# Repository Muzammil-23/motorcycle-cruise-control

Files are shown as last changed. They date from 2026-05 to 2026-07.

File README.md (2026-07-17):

# Low-Cost Cruise Control System for Honda CD70 (and similar 70-150cc motorcycles)



[]()

A retrofittable, low-cost cruise control system for small-displacement motorcycles (70-150cc) commonly found in South Asian and Southeast Asian markets. The system uses an Arduino Nano, Hall-effect speed sensor, MG996R servo, and a discrete-time PI controller to maintain a rider-set speed, and 1.2in OLED for UI. Improving comfort, fuel efficiency and reducing fatigue on long rides.

## 📋 Features

- **Closed-loop speed regulation** at 50 km/h setpoint (configurable)
- **Velocity-form PI controller** (Kp = 0.67, Ki = 0.48 s⁻¹) with 2 km/h dead-band
- **Moving average filter** (3 samples) for noise reduction
- **Safety disengagement** via brake, clutch, and kill switch
- **Hardware interrupt** for brake → fastest response (~500 ms)
- **OLED display** showing speed, setpoint, and system status
- **Bumpless transfer** on engagement/disengagement
- **Cost-effective** (~$20 USD total hardware cost)

 ## Cruise Control System installed on a motorcycle handlebar
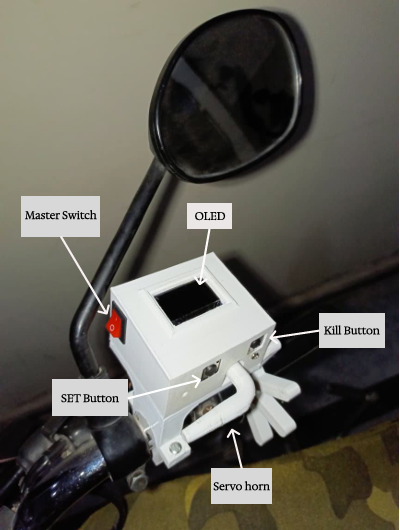
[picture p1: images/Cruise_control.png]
Cruise Control System installed on a motorcycle handlebar


## 🔧 Hardware

This project was designed using **Proteus 8 Professional** .

| Folder | Contents |
|---|---|
| `/schematic` | Proteus editable file (.pdsprj) and PDF schematic |
| `/PCB` | Gerber files (ZIP) for manufacturing and PDF layout |

## 💻 Firmware

The firmware runs on an **Arduino Nano** (ATmega328P).

**Required Libraries:**
- `Adafruit_SSD1306.h` (OLED display)
- `Adafruit_GFX.h` (graphics library)
- `Servo.h` (built-in)

**Upload Instructions:**
1. Open the `.ino` file in Arduino IDE
2. Select Board: Arduino Nano
3. Select Processor: ATmega328P
4. Upload via USB

## 🖨️ 3D Models

STL files for the enclosure and mechanical parts are in the `/3D files` folder.

**Printing Recommendations:**
- Material: ABS or PETG
- Layer height: 0.2mm
- Infill: 20%
- Supports: Yes (for specific parts - check individual files)

# Project Licensing

This project uses different licenses for different types of content:

| Content Type | License |
|---|---|
| Firmware (code in `/firmware` folder) | MIT License (see LICENSE file) |
| Hardware (schematics, PCB layouts, BOM) | CERN-OHL-P-2.0 (see LICENSE-Hardware file) |
| 3D Models (CAD files, STLs) | CERN-OHL-P-2.0 (see LICENSE-Hardware file) |

The MIT License applies ONLY to software files. The CERN-OHL-P-2.0 applies to all hardware design files.

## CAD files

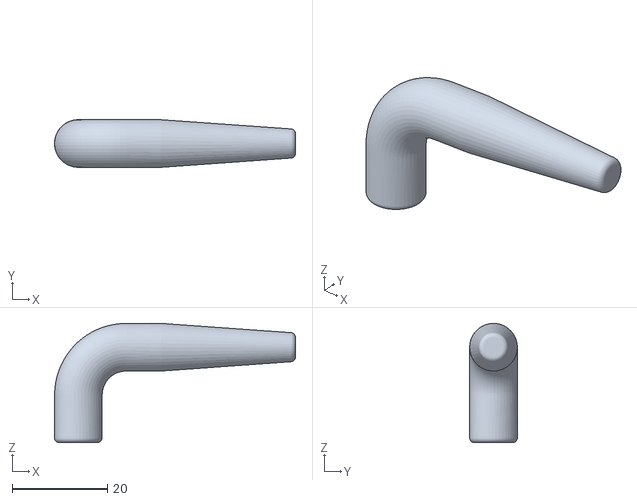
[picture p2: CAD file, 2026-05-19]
3D files/Servo horn.STL
50.5 x 10.00 x 25.0

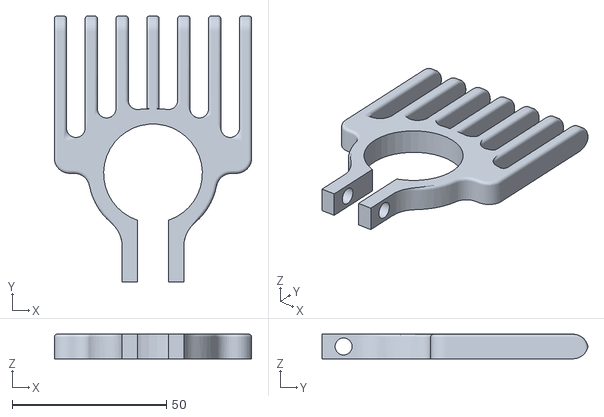
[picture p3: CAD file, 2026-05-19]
3D files/Toothed mech.STL
64.0 x 86.2 x 8.00

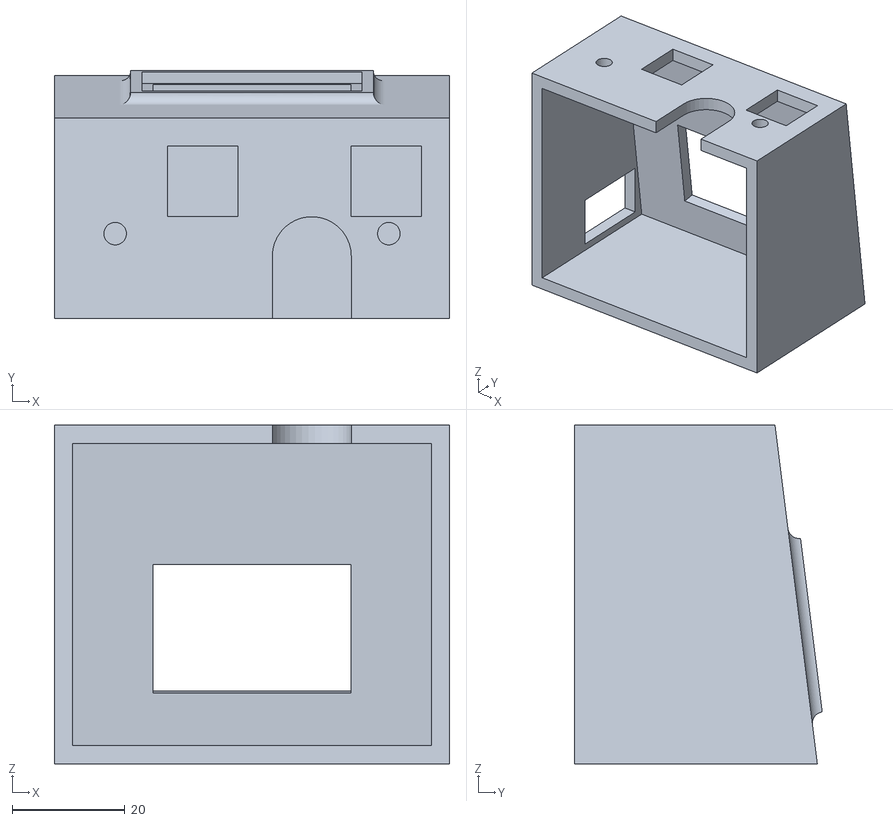
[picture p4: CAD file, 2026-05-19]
3D files/Top.STL
70.0 x 43.9 x 60.0

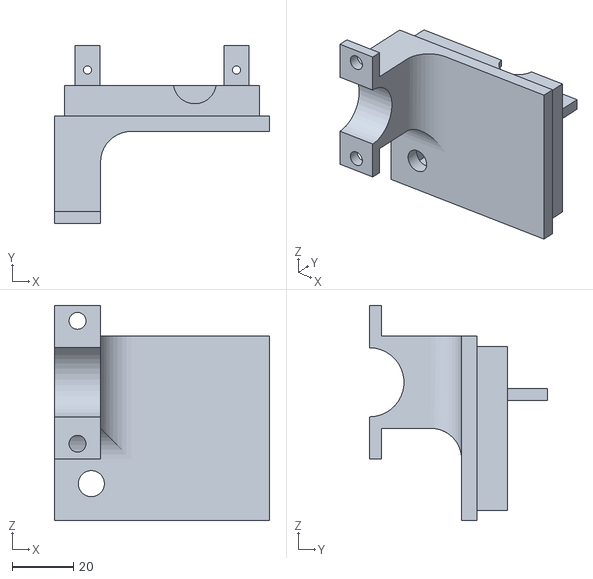
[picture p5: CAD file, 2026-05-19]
3D files/Base.STL
70.0 x 58.0 x 70.0

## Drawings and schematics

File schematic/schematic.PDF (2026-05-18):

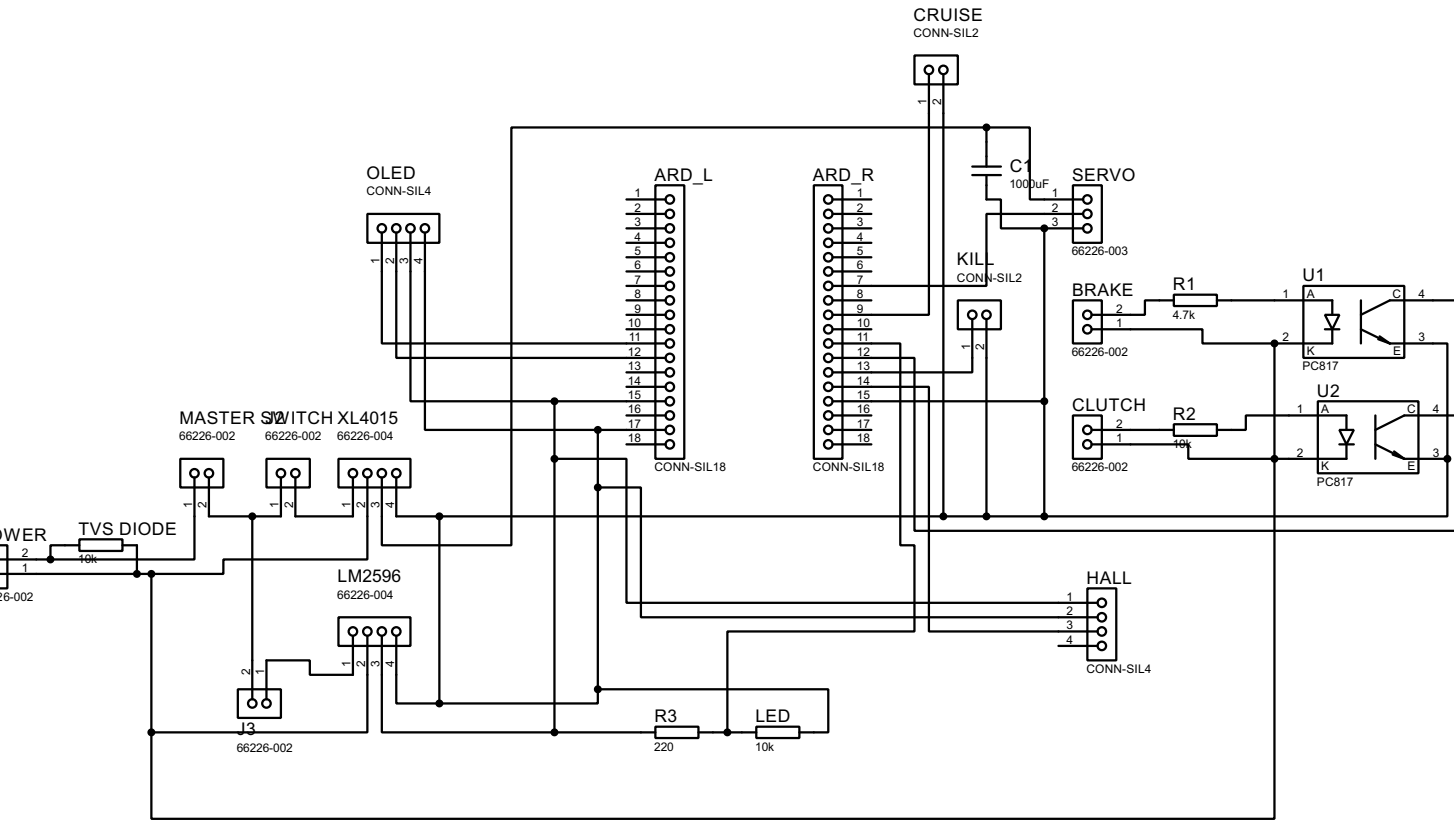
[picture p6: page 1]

12 MASTER SWITCH 66226-002 123456789101112131415161718 ARD_L CONN-SIL18 123456789101112131415161718 ARD_R CONN-SIL18 12 POWER 66226-002 1234 XL4015 66226-004 1234 LM2596 66226-0041234 OLED CONN-SIL4 123 SERVO 66226-003 1234 HALL CONN-SIL4 12 BRAKE 66226-00212 CLUTCH 66226-002 C1 1000uF 12 KILL CONN-SIL2 12 CRUISE CONN-SIL2 AK CE 12 43 U1 PC817 AK CE 12 43 U2 PC817 12 J266226-002 21 J366226-002 R1 4.7k R2 10k R3 220 LED 10k TVS DIODE 10k

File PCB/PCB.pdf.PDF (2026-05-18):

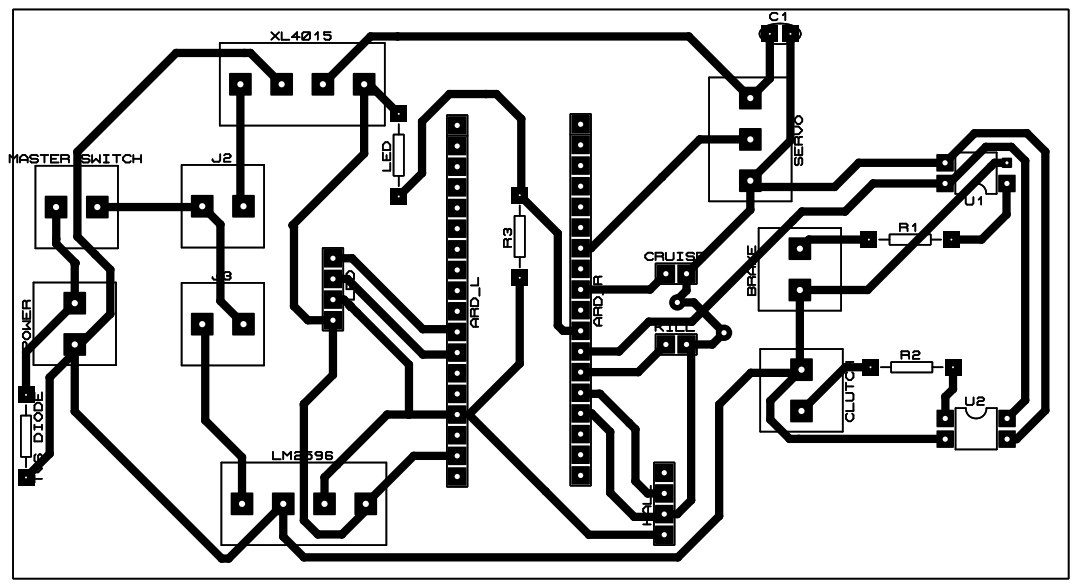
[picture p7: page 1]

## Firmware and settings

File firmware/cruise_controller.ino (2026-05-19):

#include <Servo.h>
#include <Wire.h>
#include <Adafruit_GFX.h>
#include <Adafruit_SSD1306.h>

// ============================================================================
// Pin Definitions
// ============================================================================
#define PIN_SPEED       2     // Hall effect sensor (interrupt)
#define PIN_BRAKE       3     // Brake signal (active HIGH via optocoupler)
#define PIN_CLUTCH      4     // Clutch signal (active HIGH)
#define PIN_KILL        5     // Kill switch (active HIGH)
#define PIN_SET_BTN     7     // SET button (pulldown, active HIGH)
#define PIN_SERVO       9     // Servo output

// ============================================================================
// OLED Setup (128x64, I2C address 0x3C)
// ============================================================================
#define SCREEN_WIDTH  128
#define SCREEN_HEIGHT 64
Adafruit_SSD1306 display(SCREEN_WIDTH, SCREEN_HEIGHT, &Wire, -1);

// ============================================================================
// Servo
// ============================================================================
Servo throttleServo;

// ============================================================================
// Speed Measurement Constants 
// ============================================================================
const float WHEEL_CIRCUMFERENCE_M = 1.57;
const float SPEED_CONSTANT = WHEEL_CIRCUMFERENCE_M * 3.6;  // = 5.652
// speed (km/h) = pulses_per_sec * SPEED_CONSTANT

// ============================================================================
// Controller Parameters 
// ============================================================================
const float V_REF_KPH = 50.0;           // setpoint (km/h)
const float Kp = 0.67;                  // proportional gain
const float Ki = 0.48;                  // integral gain (s^-1)
const float Ts = 0.1;                   // sampling period (100 ms)
const float DEADBAND_KPH = 2.0;         // dead-band threshold (km/h)

const int SERVO_REST = 90;
const int SERVO_MAX = 180;

// ============================================================================
// Moving Average Filter
// ============================================================================
#define FILTER_WINDOW_SIZE 3
float speed_buffer[FILTER_WINDOW_SIZE] = {0};
int buffer_index = 0;
bool buffer_filled = false;

// ============================================================================
// Global Variables
// ============================================================================
volatile unsigned long last_pulse_time = 0;
volatile float instantaneous_speed = 0.0;
volatile bool new_speed_ready = false;
volatile unsigned long pulse_interval = 0;  // store interval for safety

float filtered_speed = 0.0;
float u_current = 0.36;      
float u_prev = 0.36;
float error_prev = 0.0;
bool cruise_active = false;
unsigned long last_control_time = 0;
unsigned long last_display_update = 0;
unsigned long last_set_time = 0;

// Debounce timers
unsigned long last_brake_time = 0;
unsigned long last_clutch_time = 0;
unsigned long last_kill_time = 0;
const unsigned long DEBOUNCE_MS = 50;

// ============================================================================
// Interrupt Service Routine - Hall Effect Sensor
// ============================================================================
void onSpeedPulse() {
  unsigned long now = micros();
  unsigned long dt = now - last_pulse_time;
  last_pulse_time = now;
  
  // Only update if interval is reasonable (between 1ms and 1 second)
  if (dt > 1000 && dt < 1000000) {
    // Store interval for speed calculation in main loop
    pulse_interval = dt;
    new_speed_ready = true;
  }
}

// ============================================================================
// Helper: Map throttle command (0-1) to servo angle (90-180)
// ============================================================================
int throttleToServoAngle(float cmd) {
  // cmd: 0 = rest position (servo 90°), 1 = full throttle (servo 180°)
  int angle = SERVO_REST + (int)(cmd * (SERVO_MAX - SERVO_REST));
  return constrain(angle, SERVO_REST, SERVO_MAX);
}

// ============================================================================
// Helper: Apply throttle to servo
// ============================================================================
void setThrottle(float cmd) {
  int angle = throttleToServoAngle(cmd);
  throttleServo.write(angle);
}

// ============================================================================
// Helper: Disengage cruise (return to rest position)
// ============================================================================
void disengageCruise(const char* reason) {
  if (cruise_active) {
    cruise_active = false;
    setThrottle(0.0);           // servo to rest position
    u_current = 0.0;
    u_prev = 0.0;
    error_prev = 0.0;
    
    // Update OLED
    display.clearDisplay();
    display.setTextSize(1);
    display.setTextColor(SSD1306_WHITE);
    display.setCursor(0, 0);
    display.println("CRUISE DISENGAGED");
    display.setCursor(0, 10);
    display.println(reason);
    display.display();
    delay(500);
    
    Serial.print("DISENGAGED: ");
    Serial.println(reason);
  }
}

// ============================================================================
// Helper: Display status on OLED
// ============================================================================
void updateDisplay() {
  display.clearDisplay();
  display.setTextSize(1);
  display.setTextColor(SSD1306_WHITE);
  display.setCursor(0, 0);
  
  display.print("Speed: ");
  display.print(filtered_speed, 1);
  display.println(" km/h");
  
  display.print("Set: ");
  display.print(V_REF_KPH, 0);
  display.println(" km/h");
  
  display.print("Cruise: ");
  display.println(cruise_active ? "ON" : "OFF");
  
  if (cruise_active) {
    display.print("Throttle: ");
    display.print((int)(u_current * 100));
    display.println("%");
  }
  
  display.display();
}

// ============================================================================
// Moving Average Filter
// ============================================================================
float movingAverageFilter(float new_sample) {
  // Filter out unrealistic values
  if (new_sample < 0 || new_sample > 120) {
    return filtered_speed;  // return last valid value
  }
  
  speed_buffer[buffer_index] = new_sample;
  buffer_index = (buffer_index + 1) % FILTER_WINDOW_SIZE;
  
  if (buffer_index == 0) {
    buffer_filled = true;
  }
  
  int num_samples = buffer_filled ? FILTER_WINDOW_SIZE : buffer_index;
  if (num_samples == 0) num_samples = 1;
  
  float sum = 0;
  for (int i = 0; i < num_samples; i++) {
    sum += speed_buffer[i];
  }
  return sum / num_samples;
}

// ============================================================================
// Calculate speed from pulse interval
// ============================================================================
float calculateSpeed() {
  if (pulse_interval > 0) {
    float pulses_per_sec = 1000000.0 / (float)pulse_interval;
    float speed = pulses_per_sec * SPEED_CONSTANT;
    // Sanity check
    if (speed > 0 && speed < 120) {
      return speed;
    }
  }
  return 0.0;
}

// ============================================================================
// Discrete-Time Velocity-Form PI Controller 
// ============================================================================
float piController(float v_meas_kph, float v_ref_kph) {
  float error = v_ref_kph - v_meas_kph;
  
  // Dead-band: no control action if error is within threshold
  if (abs(error) <= DEADBAND_KPH) {
    return u_prev;
  }
  
  // Velocity-form PI update 
  float delta_u = Kp * (error - error_prev) + Ki * Ts * error;
  float u_new = u_prev + delta_u;
  
  // Clamp throttle command to [0, 1]
  if (u_new > 1.0) u_new = 1.0;
  if (u_new < 0.0) u_new = 0.0;
  
  // Update states for next iteration
  error_prev = error;
  u_prev = u_new;
  
  return u_new;
}

// ============================================================================
// Setup
// ============================================================================
void setup() {
  Serial.begin(115200);
  Serial.println("Cruise Control System Initializing...");
  
  // ------------------------- Pin Modes -------------------------
  pinMode(PIN_SPEED, INPUT_PULLUP);
  pinMode(PIN_BRAKE, INPUT);
  pinMode(PIN_CLUTCH, INPUT);
  pinMode(PIN_KILL, INPUT);
  pinMode(PIN_SET_BTN, INPUT);
  
  // ------------------------- Servo -------------------------
  throttleServo.attach(PIN_SERVO);
  setThrottle(0.0);     // start at rest position
  delay(500);
  
  // ------------------------- OLED -------------------------
  if (!display.begin(SSD1306_SWITCHCAPVCC, 0x3C)) {
    Serial.println("OLED init failed!");
  } else {
    display.clearDisplay();
    display.setTextSize(1);
    display.setTextColor(SSD1306_WHITE);
    display.setCursor(0, 0);
    display.println("Cruise Control");
    display.println("System Ready");
    display.display();
  }
  
  // ------------------------- Interrupt -------------------------
  attachInterrupt(digitalPinToInterrupt(PIN_SPEED), onSpeedPulse, RISING);
  
  // Initialize timing
  last_control_time = millis();
  last_display_update = millis();
  
  Serial.println("System Ready. Press SET to engage at 50 km/h");
  Serial.println("Speed (km/h), Throttle, Cruise State");
}

// ============================================================================
// Main Loop
// ============================================================================
void loop() {
  unsigned long now = millis();
  
  // ------------------------- Read Speed from ISR -------------------------
  if (new_speed_ready) {
    new_speed_ready = false;
    float raw_speed = calculateSpeed();
    
    // Apply moving average filter
    filtered_speed = movingAverageFilter(raw_speed);
  }
  
  // ------------------------- Safety Disengagement -------------------------
  // Brake check (active HIGH)
  if (digitalRead(PIN_BRAKE) == HIGH) {
    if (now - last_brake_time > DEBOUNCE_MS) {
      last_brake_time = now;
      if (cruise_active) {
        disengageCruise("BRAKE APPLIED");
      }
    }
  }
  
  // Clutch check (active HIGH)
  if (digitalRead(PIN_CLUTCH) == HIGH) {
    if (now - last_clutch_time > DEBOUNCE_MS) {
      last_clutch_time = now;
      if (cruise_active) {
        disengageCruise("CLUTCH ENGAGED");
      }
    }
  }
  
  // Kill switch check (active HIGH)
  if (digitalRead(PIN_KILL) == HIGH) {
    if (now - last_kill_time > DEBOUNCE_MS) {
      last_kill_time = now;
      if (cruise_active) {
        disengageCruise("KILL SWITCH ACTIVATED");
      }
    }
  }
  
  // ------------------------- SET Button -------------------------
  if (digitalRead(PIN_SET_BTN) == HIGH) {
    if (now - last_set_time > 500) {  // 500ms debounce
      last_set_time = now;
      
      if (!cruise_active) {
        // Engagement condition: speed >= 40 km/h 
        if (filtered_speed >= 40.0) {
          cruise_active = true;
          
          // Bumpless transfer: initialize controller states with current throttle
          error_prev = V_REF_KPH - filtered_speed;
          u_prev = u_current;
          
          Serial.print("CRUISE ENGAGED at ");
          Serial.print(filtered_speed);
          Serial.println(" km/h");
          
          display.clearDisplay();
          display.setTextSize(1);
          display.setCursor(0, 0);
          display.println("CRUISE ACTIVE");
          display.setCursor(0, 10);
          display.print("Setpoint: ");
          display.print(V_REF_KPH, 0);
          display.println(" km/h");
          display.display();
          delay(1000);
        } else {
          // Speed too low for cruise engagement
          display.clearDisplay();
          display.setTextSize(1);
          display.setCursor(0, 0);
          display.print("Speed too low!");
          display.setCursor(0, 10);
          display.print("Need >40 km/h");
          display.display();
          delay(1000);
        }
      } else {
        // Manual disengagement via SET button (kill switch alternative)
        disengageCruise("MANUAL DISENGAGEMENT");
      }
    }
  }
  
  // ------------------------- Control Loop (every Ts = 100 ms) -------------------------
  if ((now - last_control_time) >= (Ts * 1000)) {
    last_control_time = now;
    
    if (cruise_active) {
      // Compute new throttle command using PI controller
      u_current = piController(filtered_speed, V_REF_KPH);
      
      // Apply throttle to servo
      setThrottle(u_current);
      
      // Log data for Serial monitoring
      Serial.print(filtered_speed);
      Serial.print(",");
      Serial.print(u_current);
      Serial.print(",");
      Serial.println(cruise_active ? "1" : "0");
    }
  }
  
  // ------------------------- Update Display (every 200 ms) -------------------------
  if ((now - last_display_update) >= 200) {
    last_display_update = now;
    updateDisplay();
  }
  
  // Small delay to prevent excessive CPU usage
  delay(5);
}

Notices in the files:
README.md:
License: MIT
